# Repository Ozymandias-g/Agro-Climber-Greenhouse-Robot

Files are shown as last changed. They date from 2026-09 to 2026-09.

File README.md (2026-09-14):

# Agro-Climber-Greenhouse-Robot
CAD design, FEA static analysis, and mechanical assembly of the Agro-Climber robot for automated plant monitoring in greenhouse environments, modeled in SolidWorks.

# Agro-Climber: Autonomous Greenhouse Monitoring Robot

## 📌 Project Overview
The **Agro-Climber** is a specialized climbing robot designed to enhance operational efficiency and make plant monitoring autonomous, precise, and cost-effective in modern greenhouse environments. It travels along greenhouse suspension cables and pipes to collect environmental and crop health data without compacting soil.

* **Course:** Computer-Aided Design (CAD)
* **Team Members:** Hamza Yiğit Yazıcı, Derviş Kekeç, Eren Burak İşler
* **Date:** January 2026

---

## ⚙️ Key Technical Features

* **Adaptive Clamping & Suspension:** 
  Modeled with custom high-precision springs using SolidWorks Helix/Spiral features. The spring-loaded suspension system absorbs ground and cable vibrations, protecting sensitive sensor payloads and ensuring smooth movement across varying cable diameters.
* **Transmission Unit:** 
  Utilizes spiral bevel gears designed for high torque delivery during vertical climbing and horizontal cable transitions.
* **Traction Wheels:** 
  Custom tread-pattern wheel profiles modeled to prevent slipping in humid, muddy greenhouse conditions.
* **Material Selection:**
  * **POM (Polyoxymethylene / Acetal):** High dimensional stability, low friction, and excellent resistance to greenhouse humidity.
  * **AISI 304 Stainless Steel:** High corrosion resistance for structural fasteners, shafts, and mounting brackets.
  * **Tires:** Matte rubber for maximum grip.
* **Total Assembly Mass:** ~9.42 kg (9,418.52 g)

---

## 🔬 FEA & Static Stress Analysis

A linear static analysis was conducted on the main body in SolidWorks Simulation to evaluate stress distribution under maximum expected operational loads:
* **Material Model:** Linear Elastic Isotropic (POM Acetal Copolymer)
* **Tensile Strength:** $7.15 \times 10^7\text{ N/m}^2$
* **Elastic Modulus:** $2.60 \times 10^9\text{ N/m}^2$
* **Applied Load:** $1000\text{ N}$ normal force on critical mounting flanges.
* **Result:** von Mises stresses remained within allowable material thresholds, confirming the structural integrity of the frame.

---

## 🛠️ Assembly Breakdown
The robot assembly consists of:
* Main Structural Body & Holders
* Drive Engine & Spiral Bevel Gear Mechanism
* Tensioning Cylinder & Holder
* Grooved Cable Climbing Wheels
* Shock-Absorbing Spring Assemblies
* Guidance Pipe Clamps

---

## 🚀 Future Recommendations
* **AI Vision Integration:** Mounting high-resolution camera modules with onboard edge computing for real-time plant disease detection.
* **Power Optimization:** Refining gear reduction ratios to maximize battery endurance during continuous vertical ascents.

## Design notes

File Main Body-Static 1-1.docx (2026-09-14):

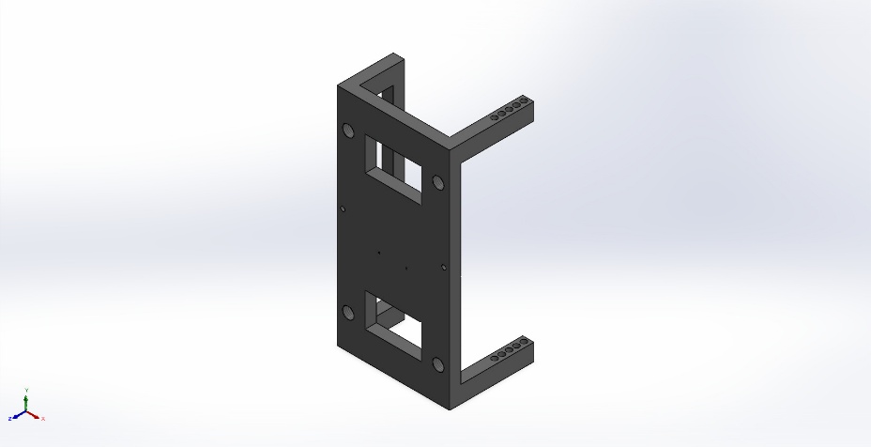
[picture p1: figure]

Simulation of Main Body

Date: 5 Ocak 2026 Pazartesi
Designer: Solidworks

Study name: Static 1

Analysis type: Static
Description No Data

# Assumptions

# Model Information

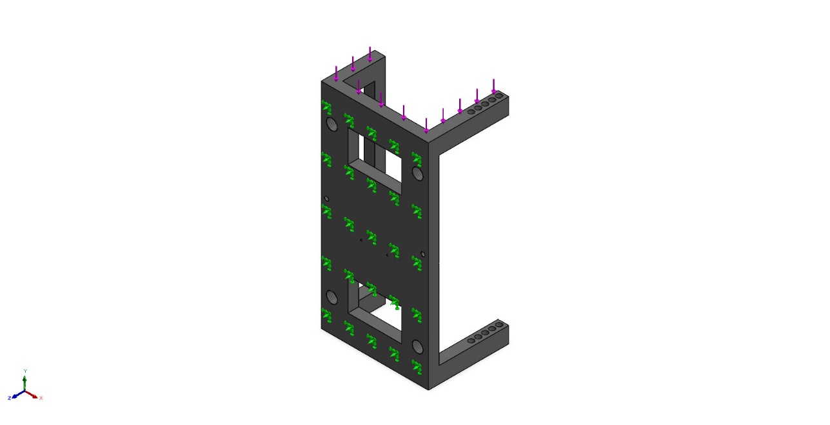
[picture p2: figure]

Model name: Main Body

Current Configuration: Default

Solid Bodies
Document Name and Reference | Treated As | Volumetric Properties | Document Path/Date Modified

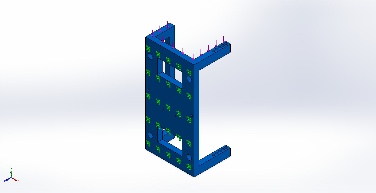
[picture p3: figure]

Mirror1 | Solid Body | Mass:2,35535 kg Volume:0,0016945 m^3 Density:1.390 kg/m^3 Weight:23,0825 N | C:\Users\victus tr\OneDrive\Masaüstü\Kmd project\Main Body.SLDPRT Jan 4 20:11:04 2026

# Study Properties

Study name | Static 1
Analysis type | Static
Mesh type | Solid Mesh
Thermal Effect: | On
Thermal option | Include temperature loads
Zero strain temperature | 298 Kelvin
Include fluid pressure effects from SOLIDWORKS Flow Simulation | Off
Solver type | Automatic
Inplane Effect: | Off
Soft Spring: | Off
Inertial Relief: | Off
Incompatible bonding options | Automatic
Contact penalty stiffness scale factor | 1
Large displacement | Off
Compute free body forces | On
Friction | Off
Use Adaptive Method: | Off
Result folder | SOLIDWORKS document (C:\Users\victus tr\OneDrive\Masaüstü\Kmd project)

# Units

Unit system: | SI (MKS)
Length/Displacement | mm
Temperature | Kelvin
Angular velocity | Rad/sec
Pressure/Stress | N/m^2

# Material Properties

Model Reference | Properties | Components

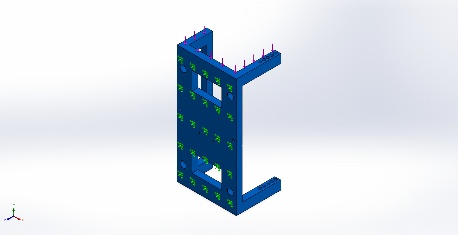
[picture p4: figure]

| Name: POM Acetal Copolymer Model type: Linear Elastic Isotropic Default failure criterion: Unknown Tensile strength: 7,15e+07 N/m^2 Elastic modulus: 2,6e+09 N/m^2 Poisson's ratio: 0,3859 Mass density: 1.390 kg/m^3 Shear modulus: 9,328e+08 N/m^2 | SolidBody 1(Mirror1)(Main Body)

Curve Data:N/A

# Loads and Fixtures

Fixture name | Fixture Image | Fixture Details

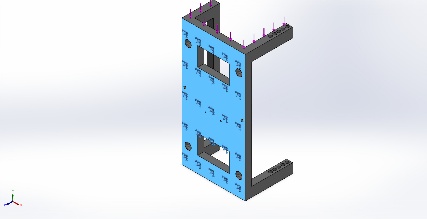
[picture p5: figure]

Fixed-1 | | Entities: 1 face(s) Type: Fixed Geometry

Resultant Forces

Components | X | Y | Z | Resultant
Reaction force(N) | -0,155434 | 1.000,08 | 0,15987 | 1.000,08
Reaction Moment(N.m) | 0 | 0 | 0 | 0

Load name | Load Image | Load Details

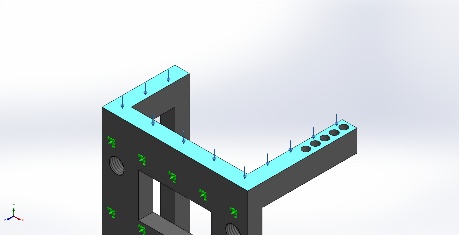
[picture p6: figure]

Force-1 | | Entities: 1 face(s) Type: Apply normal force Value: 1.000 N

# Connector Definitions

No Data

# Interaction Information

No Data

# Mesh information

Mesh type | Solid Mesh
Mesher Used: | Blended curvature-based mesh
Jacobian points for High quality mesh | 16 Points
Maximum element size | 23,849 mm
Minimum element size | 1,19245 mm
Mesh Quality | High

## Mesh information - Details

Total Nodes | 31311
Total Elements | 18509
Maximum Aspect Ratio | 6,7677
% of elements with Aspect Ratio < 3 | 96,1
Percentage of elements with Aspect Ratio > 10 | 0
Percentage of distorted elements | 0
Time to complete mesh(hh;mm;ss): | 00:00:03
Computer name: | VICTUSINYO

## Mesh Quality Plots

Name | Type | Min | Max
Quality1 | Mesh | - | -

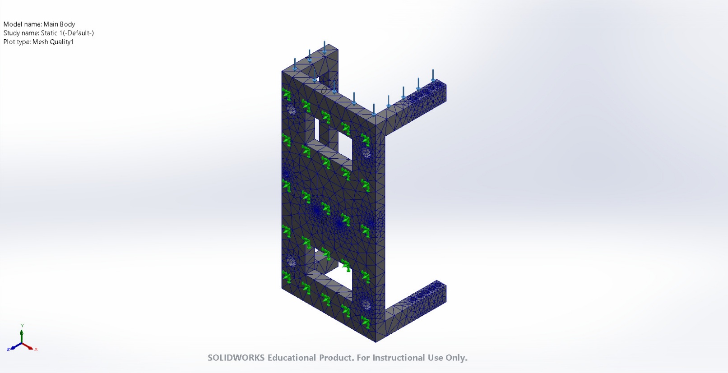
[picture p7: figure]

Main Body-Static 1-Quality-Quality1

# Sensor Details

No Data

# Resultant Forces

## Reaction forces

Selection set | Units | Sum X | Sum Y | Sum Z | Resultant
Entire Model | N | -0,155434 | 1.000,08 | 0,15987 | 1.000,08

## Reaction Moments

Selection set | Units | Sum X | Sum Y | Sum Z | Resultant
Entire Model | N.m | 0 | 0 | 0 | 0

## Free body forces

Selection set | Units | Sum X | Sum Y | Sum Z | Resultant
Entire Model | N | -1,04055 | 0,453825 | -0,0323126 | 1,13567

## Free body moments

Selection set | Units | Sum X | Sum Y | Sum Z | Resultant
Entire Model | N.m | 0 | 0 | 0 | 1e-33

# Beams

No Data

# Study Results

Name | Type | Min | Max
Stress1 | VON: von Mises Stress | 7,705e-05N/m^2 Node: 27892 | 5,508e+06N/m^2 Node: 9717

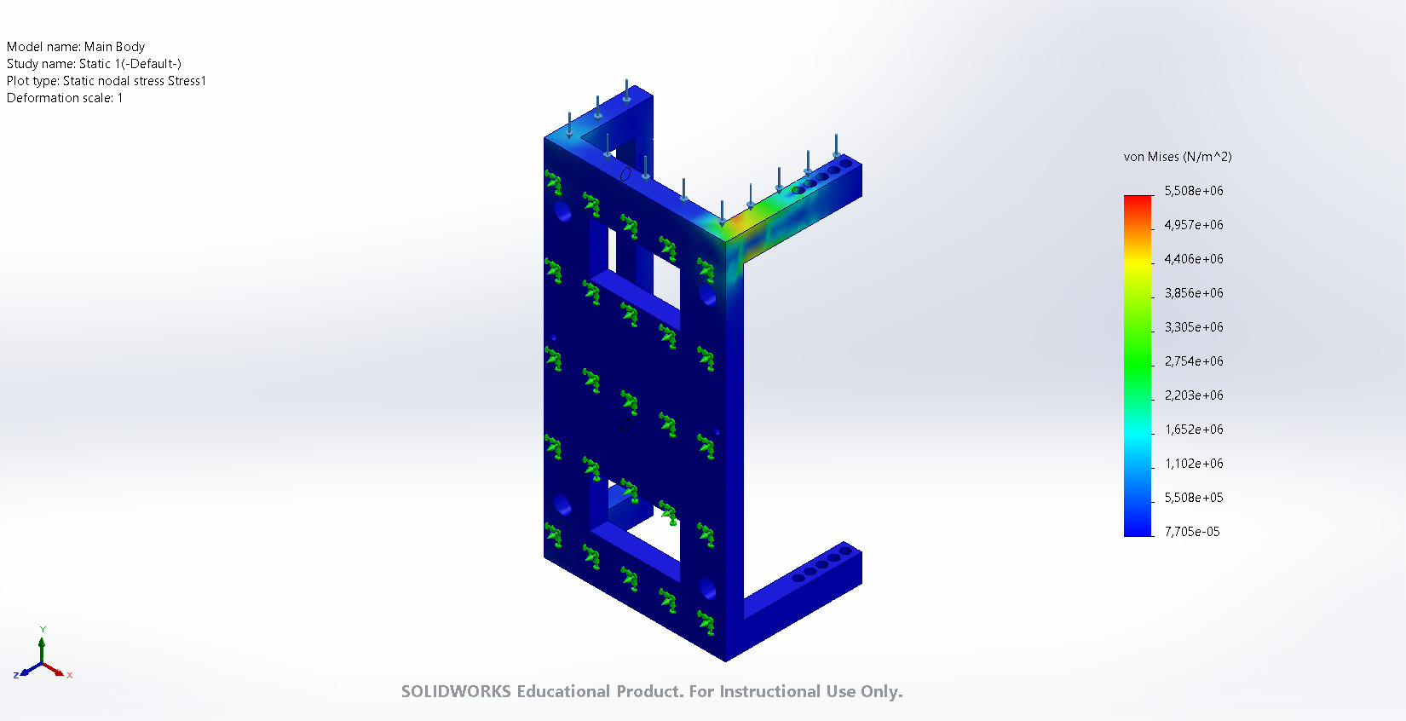
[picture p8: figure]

Main Body-Static 1-Stress-Stress1

Name | Type | Min | Max
Displacement1 | URES: Resultant Displacement | 0,000e+00mm Node: 1 | 8,427e-01mm Node: 10

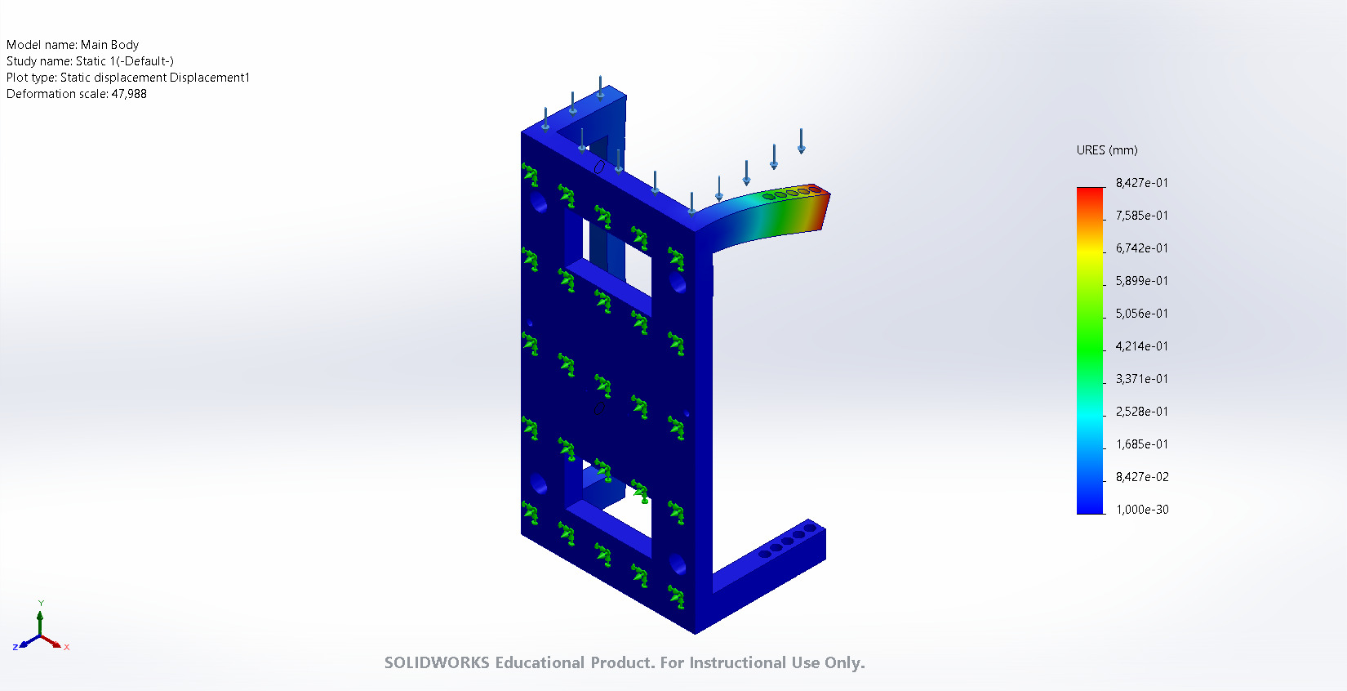
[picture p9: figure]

Main Body-Static 1-Displacement-Displacement1

Name | Type | Min | Max
Strain1 | ESTRN: Equivalent Strain | 1,512e-14 Element: 18063 | 1,524e-03 Element: 13237

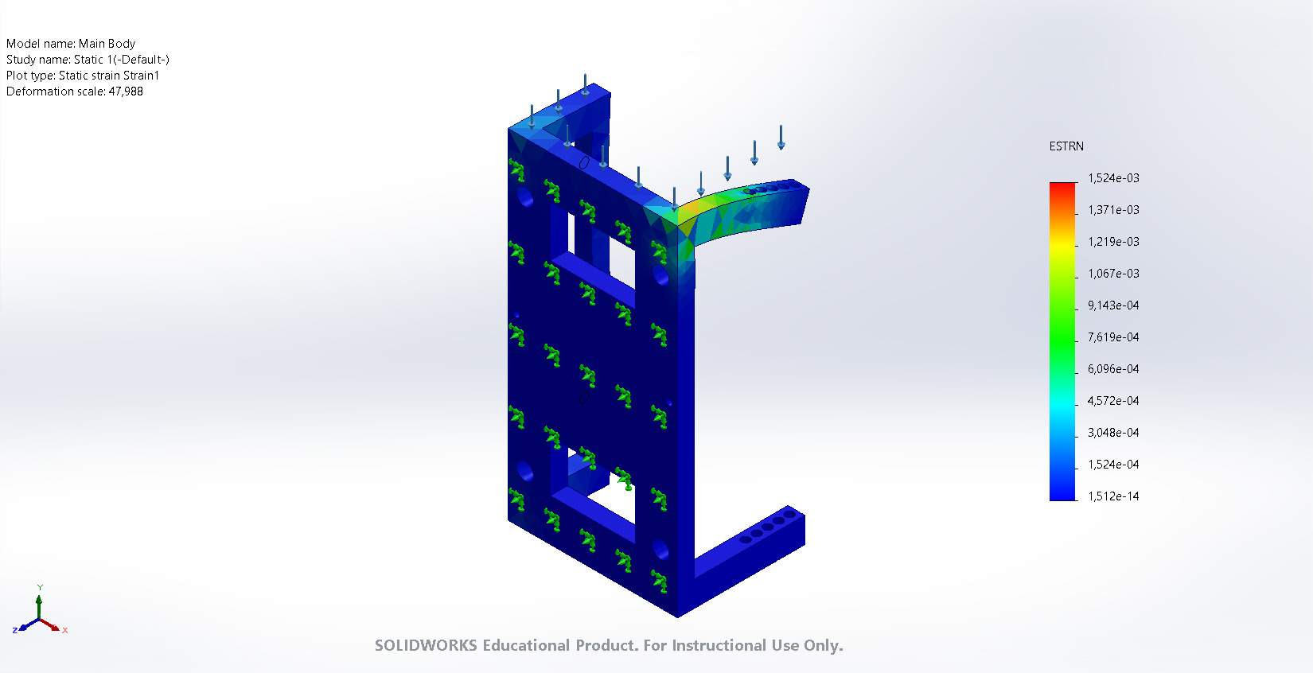
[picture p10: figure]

Main Body-Static 1-Strain-Strain1

# Conclusion

Analyzed with SOLIDWORKS Simulation Simulation of Main Body 16

Analyzed with SOLIDWORKS Simulation Simulation of Main Body 1

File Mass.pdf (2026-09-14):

Mass properties ofAssembly_Project Configuration: Default
Coordinate system: -- default --

Mass = 9418.52 grams

Volume = 5574996.85 cubic millimeters

Surface area = 986599.90 square millimeters

Center of mass: ( millimeters )
X = 804.75
Y = 779.18
Z = 161.44

Principal axes of inertia and principal moments of inertia: ( grams * square millimeters ) aTken at the center of mass.
Ix = (-0.43, 0.90, 0.01) | Px = 103786247.69
Iy = (-0.90, -0.43, 0.09) | Py = 220700789.89
Iz = ( 0.09, 0.03, 1.00) | Pz = 227628664.41

Moments of inertia: ( grams * square millimeters )
aTken at the center of mass and aligned with the output coordinate system. (Using positive tensor notation.) Lxx = 198903402.59 Lxy = -45592795.95 Lxz = -178685.22 Lyx = -45592795.95 Lyy = 125659417.97 Lyz = 969874.48
Lzx = -178685.22 | Lzy = 969874.48 | Lzz = 227552881.42

Moments of inertia: ( grams * square millimeters )
aTken at the output coordinate system. (Using positive tensor notation.)
Ixx = 30374449173.87 | Ixy = 5860205754.02Ixz = 12212728885.27
Iyx = 5860205754.02Iyy = 30682601396.87 | Iyz = 1826856352.91
Izx = 12212728885.27 | Izy = 1826856352.91 | Izz = 12045306014.68

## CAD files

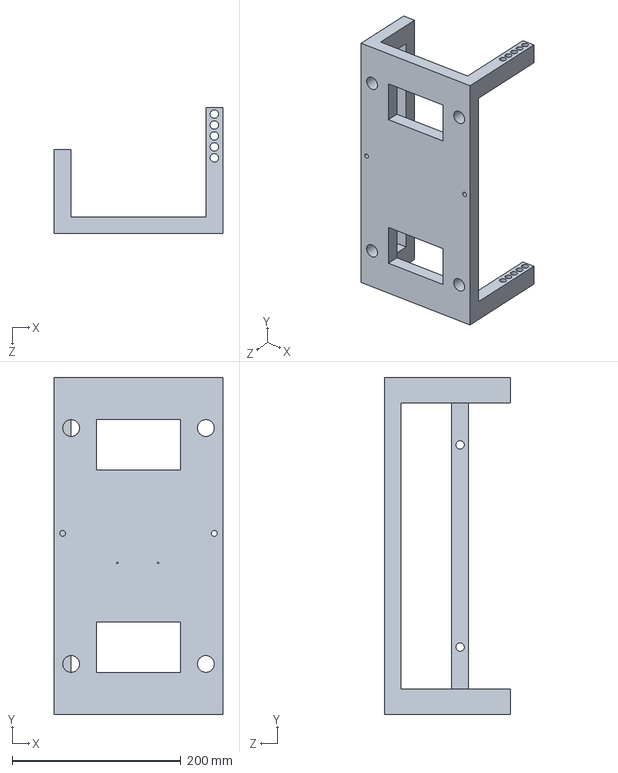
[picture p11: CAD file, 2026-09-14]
Main Body.SLDPRT
200.0 x 400.0 x 150.0 mm

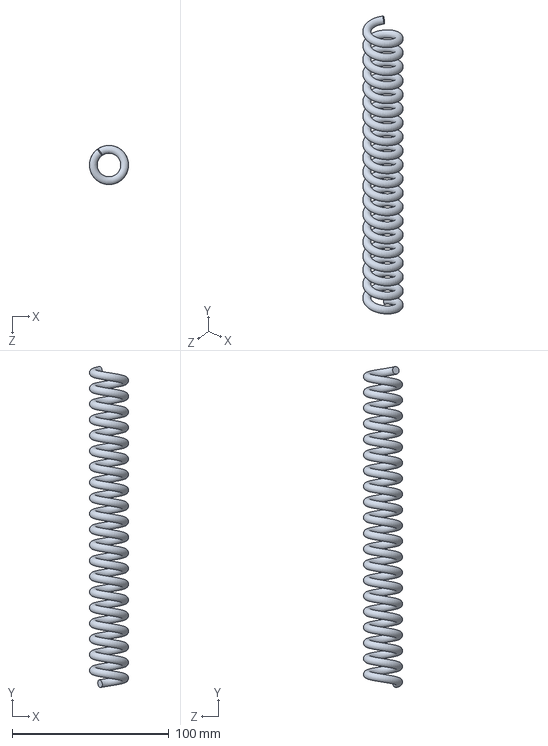
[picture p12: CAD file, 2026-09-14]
Spring.SLDPRT
25.0 x 204.9 x 25.0 mm

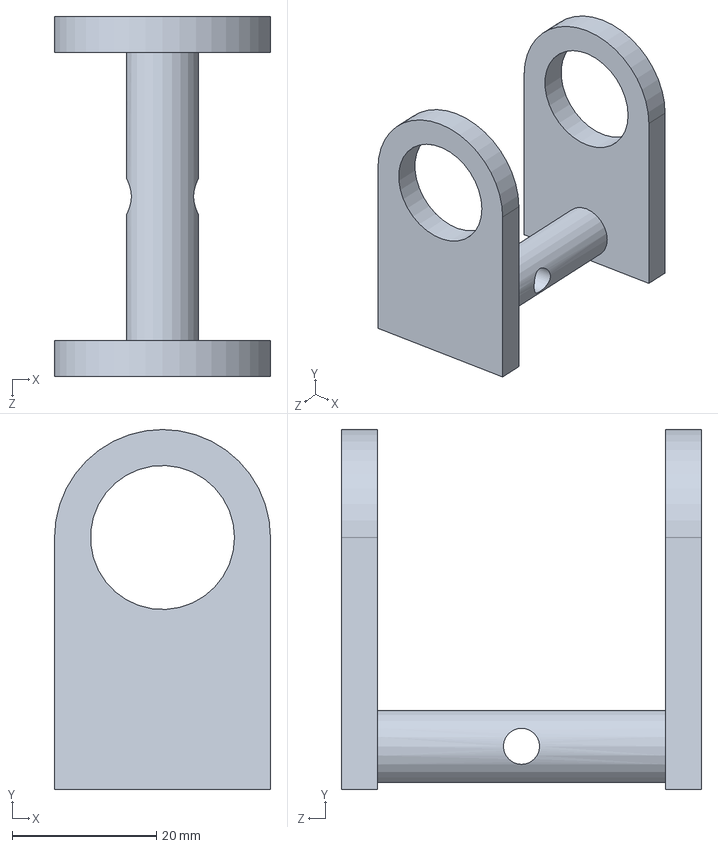
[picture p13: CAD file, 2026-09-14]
Spring Holder.SLDPRT
30.0 x 50.0 x 50.0 mm

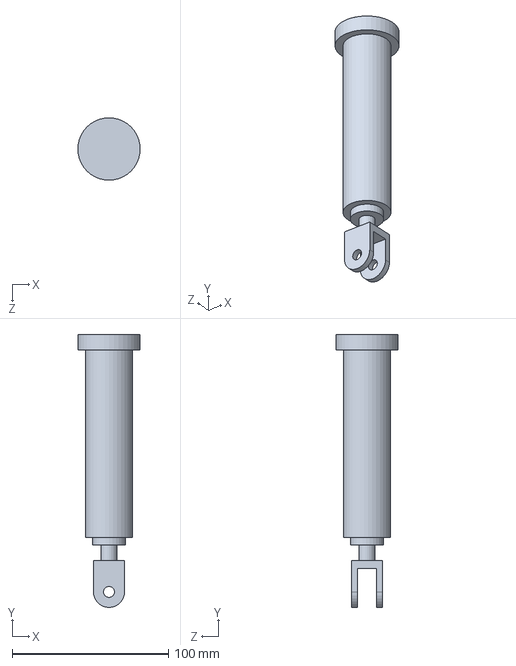
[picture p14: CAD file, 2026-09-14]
Cylinder.SLDPRT
40.0 x 175.0 x 40.0 mm

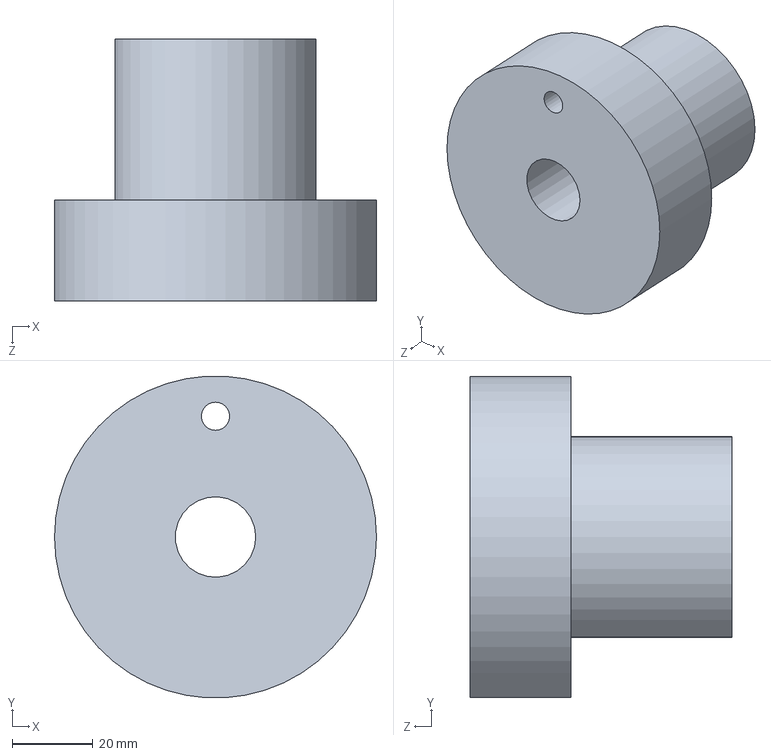
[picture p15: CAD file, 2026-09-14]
Cylinder Wheel.SLDPRT
80.0 x 79.8 x 65.0 mm

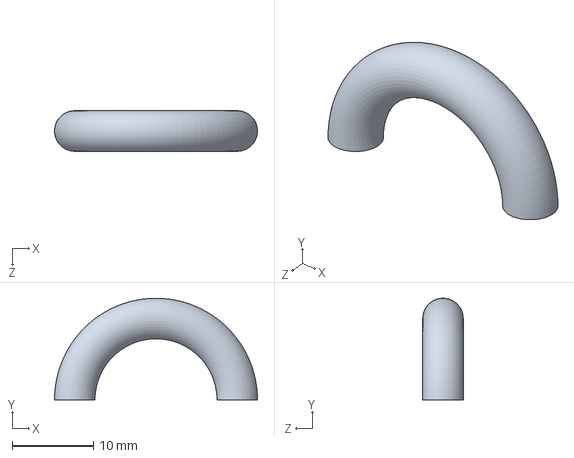
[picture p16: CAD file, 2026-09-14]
Spring_v2.SLDPRT
25.0 x 12.5 x 5.00 mm

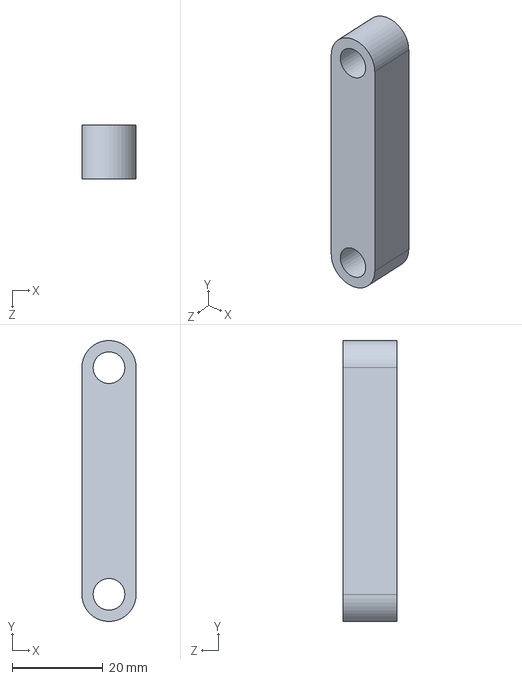
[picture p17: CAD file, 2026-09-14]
Cylinder Attachment.SLDPRT
12.0 x 62.0 x 12.0 mm

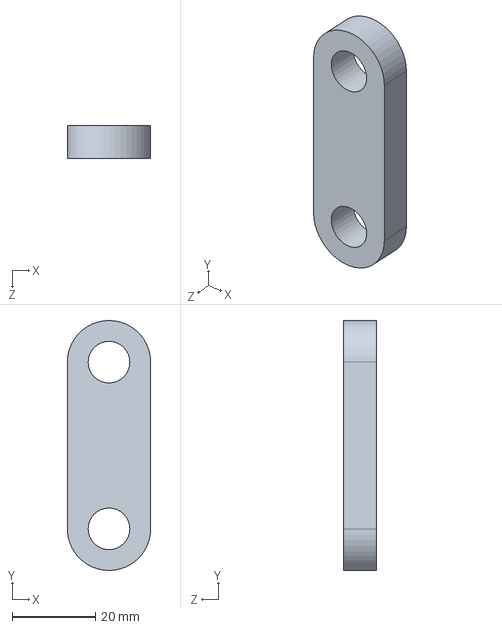
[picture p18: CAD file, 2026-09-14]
Body Holder.SLDPRT
20.0 x 60.0 x 8.00 mm

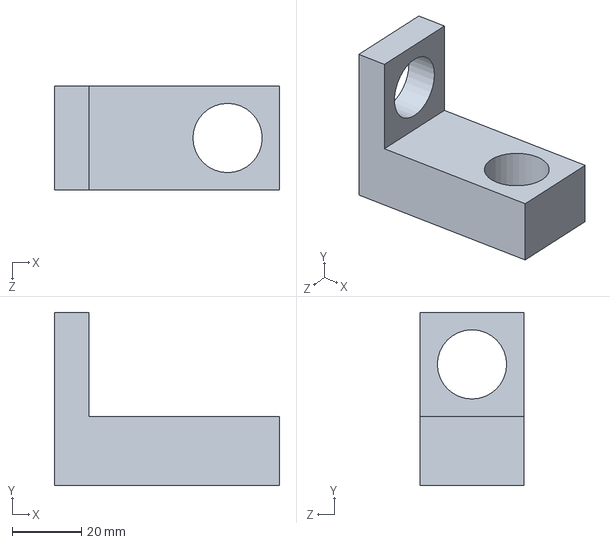
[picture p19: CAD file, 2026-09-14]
Wheel Holder.SLDPRT
65.0 x 50.0 x 30.0 mm

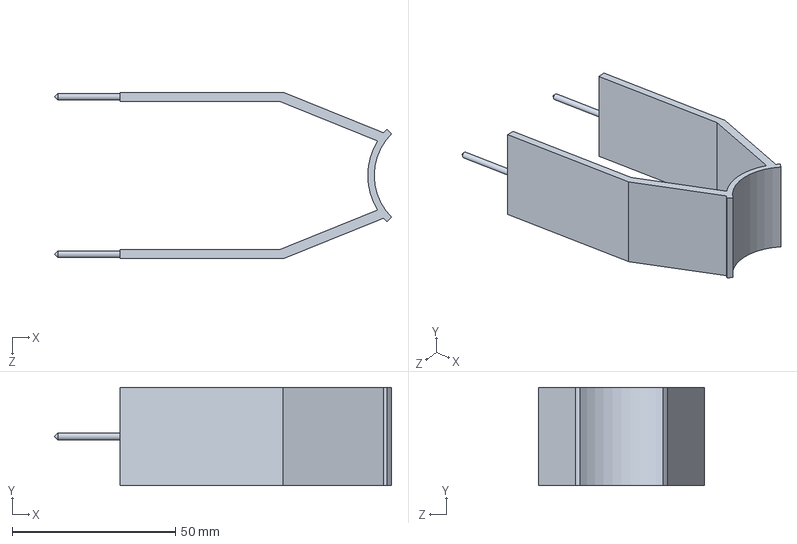
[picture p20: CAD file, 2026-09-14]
Pipe Holder_v1.SLDPRT
103.1 x 30.0 x 50.9 mm

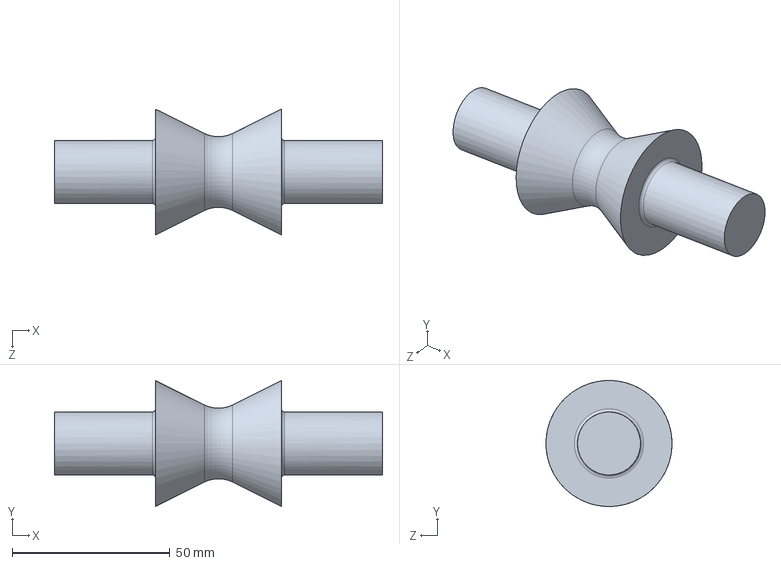
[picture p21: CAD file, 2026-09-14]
Wheel.SLDPRT
104.0 x 40.0 x 40.0 mm

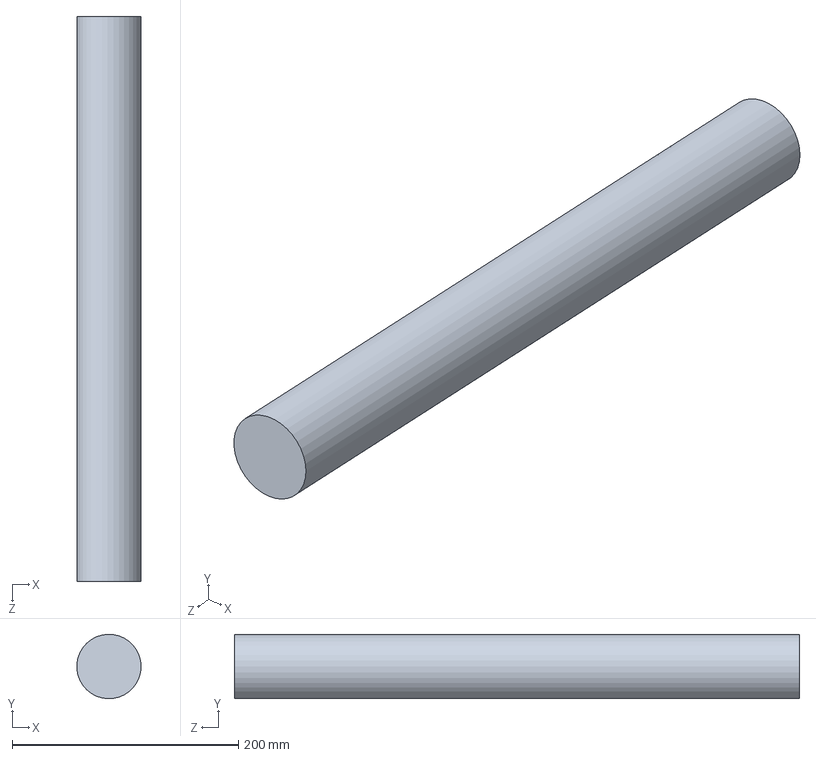
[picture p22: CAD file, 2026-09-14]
Pipe.SLDPRT
56.9 x 56.9 x 500.0 mm

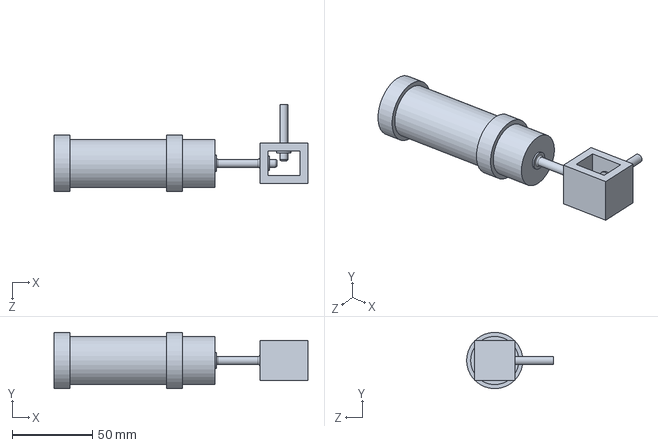
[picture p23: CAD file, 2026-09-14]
Engine.SLDPRT
158.0 x 35.0 x 54.0 mm

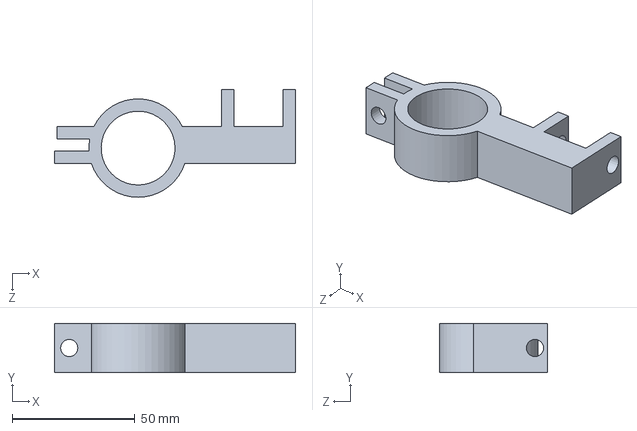
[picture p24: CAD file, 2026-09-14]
Cylinder Holder.SLDPRT
98.0 x 20.0 x 43.7 mm

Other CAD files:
Assembly_Project.SLDASM
Assembly_Project.SLDDRW
